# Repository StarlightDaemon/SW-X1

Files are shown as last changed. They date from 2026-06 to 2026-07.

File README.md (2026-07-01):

# Sidewinder X1 — Firmware & Tooling Maintenance Workspace

Locally-owned maintenance record for **one** Artillery Sidewinder X1 (Gen 1 Rev 1) being
recommissioned after ~5 years in storage. Self-contained: verified firmware source +
binaries, a documented configuration diff, matching TFT firmware, printed-part files,
wiring docs, and full upstream backups — all under this repo's control, independent of any
upstream GitHub repo's future activity.

> **Governing rule:** trust the hardware (`M115`/`M119`/`G29`) and the actual file
> contents — never a filename, README, or changelog. This ecosystem has repeatedly
> mislabeled capability. See [docs/verification-log.md](docs/verification-log.md).

---

## ▶ Start here
**[docs/GUIDE.md](docs/GUIDE.md)** — the ordered end-to-end build guide (parts → print →
wire → flash → verify → calibrate → map the warp). Everything below is reference for it.

## ⚠️ Headline finding (read before flashing anything)
The BLTouch build the project planned to flash — dgtaheno **`Marlin 2.1.2.1-X1-BLT.hex`** —
is **NOT Waggster-compatible as shipped.** Its `Configuration.h` leaves
`Z_MIN_PROBE_USES_Z_MIN_ENDSTOP_PIN` active *and* sets `Z_MIN_PROBE_PIN 19`, which
contradict: Marlin reads the probe on **Z-MIN**, not the **Z-MAX/pin-19** port the
Waggster mod wires to. Flashed as-is, the probe would never be seen.

**Flash instead — both ready now** (see [docs/install-runbook.md](docs/install-runbook.md)):
1. ★ **`firmware/build--X1-BLT-2.1.2.1-waggster-fixed/Marlin-2.1.2.1-X1-BLT-waggster-fixed.hex`**
   — dgtaheno's X1-BLT **rebuilt this session with the probe fix** (line 1279 commented →
   probe on Z-MAX/pin 19). Marlin 2.1.2.1, exact X1 geometry, compiled clean & verified. **or**
2. `firmware/reference--digant73-2.0.9.1-waggster-zmax/firmware.hex` — prebuilt, correct out
   of the box (UBL 7×7 — better for a heavily warped bed).

Then **verify on hardware** (`M119` probe toggle, `G29`) before trusting it.

## Current state of the printer
| | |
|---|---|
| Running firmware | Marlin 2.1.2.1, dgtaheno **X1 non-BLT** (`Marlin 2.1.2.1-X1.hex`), Oct 14 2023 |
| Leveling | **None compiled in** (verified via `M115`: `Cap:AUTOLEVEL:0`, `Z_PROBE:0`; `G29`→Unknown) |
| TFT | MKS TFT28 V4.0.27.x, dgtaheno companion build |
| Host | COM3 @ 250000, CH340; TFT "Disconnect" mode needed for host access |
| Calibration (live) | Hotend PID 17.07/1.51/48.25 · Bed PID 44.56/7.25/182.52 · E-steps 440.87 |

Hardware details: [docs/hardware-baseline.md](docs/hardware-baseline.md).
Calibration to preserve across reflash: [docs/calibration-baseline.md](docs/calibration-baseline.md).

## What's planned
Add a **genuine ANTCLABS BLTouch v3.1** via the **Waggster mod** (probe signal → Z-MAX /
pin 19, reusing the LED ribbon path; sacrifices the extruder LED). Sensor + 2 m cable
ordered. Mount in PETG; fan-duct remix on standby. Wiring: [wiring/README.md](wiring/README.md).

## Repository map
```
README.md                     ← you are here
docs/
  GUIDE.md                     ★ master ordered build guide — start here
  hardware-baseline.md         canonical hardware facts (do not re-derive)
  calibration-baseline.md      live PID / e-steps + host connection notes
  verification-log.md          M115 ground truth + source-inspection proofs ★
  configuration-diff.md        8-build comparison matrix + customizations ★
  open-questions.md            Q1/Q2/Q3 answered + remaining hardware items
  decisions.md                 decisions + rationale
  install-runbook.md           ★ flash-day step-by-step: wire → flash → verify → calibrate
firmware/
  running--dgtaheno-X1-nonBLT/      what's on the printer now (hex + headers)
  target--dgtaheno-X1-BLT/          as-shipped (⚠ probe forced to Z-MIN — do not flash)
  build--X1-BLT-2.1.2.1-waggster-fixed/  ★ recommended flash: X1-BLT rebuilt w/ probe fix
  reference--dgtaheno-Genius-BLT/   correct z-max routing but Genius bed (220²)
  reference--digant73-2.0.9.1-waggster-zmax/  ★ correct Waggster build (source+hex+pins)
  reference--digant73-2.0.9.1-mbl/  manual-mesh reference
  reference--peterrakolcza-2.1.2/   2.1.2-era binaries (no source)
  reference--artillery3d-stock/     manufacturer stock reference
  NOTES.md                          firmware map + MD5 fingerprints
tft-firmware/                  matching dgtaheno TFT update + a BTT-based option
printed-parts/                 mount+duct STLs (all vendored) — see BLTOUCH-MOUNT-OPTIONS.md
  waggster-bltouch-mount-duct/   Option A: blinkybill integrated mount+duct
  waggster-bltouch-mount/ + fan-duct-remix/  Option B: Waggster mount + alguiens duct
wiring/                        Waggster Mod - BLTouch v1.5.pdf + pin-mapping notes
calibration/                   Reset Settings.gcode (EEPROM reset)
archive/
  upstream-bundles/            full git bundles of all 4 upstreams (complete backup)
  SOURCES.md                   repo URLs, cloned commit SHAs, restore instructions
```
★ = start here.

## Next actions (in order)
> Flash-day checklist with exact commands: **[docs/install-runbook.md](docs/install-runbook.md)**.
1. Print Waggster mount (PETG); test-fit against the stock fan duct.
2. Wire the BLTouch per [wiring/README.md](wiring/README.md) (probe → Z-MAX/pin 19).
3. Flash a **correct** Waggster build (see Headline finding). Run the EEPROM reset
   (`calibration/Reset Settings.gcode` or `M502/M500`).
4. **Verify on hardware:** `M115` (Cap:Z_PROBE:1), `M119` (probe toggles), `G29` (runs).
5. Re-apply live calibration (`M301`/`M304`/`M92` then `M500`).
6. Set `M851` Z-offset; measure `NOZZLE_TO_PROBE_OFFSET` for the actual mount.
7. **Then** map the real bed warp (still unmeasured — see hardware-baseline.md).

## Deferred / out of scope
Z lead-screw lubrication; plastic→aluminium idler swap; all-metal heatbreak (current
~240 °C cap); empirical bed-warp mapping. **Out of scope:** Klipper/RPi/32-bit migration,
CNC tooling, 3D-modeling workflow.

## Provenance
All four upstreams cloned **2026-06-30**; commit SHAs and bundle-restore instructions in
[archive/SOURCES.md](archive/SOURCES.md). Firmware fingerprints in
[firmware/NOTES.md](firmware/NOTES.md).

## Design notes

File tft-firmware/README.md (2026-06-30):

# TFT firmware (MKS TFT28 V4.0)

Two TFT firmware options are collected here. They are **different firmware families** —
read before flashing.

## 1. `dgtaheno-SD-TFT-update.zip` — the matching companion (use this one to stay in sync)
This is the TFT firmware that **pairs with the dgtaheno Marlin build currently on the
printer** (MKS TFT28 V4.0.27.x era). It is the in-sync option: flash via SD card (copy
contents to SD root, power on, wait for the flash, reboot). MD5 `2efd1b209a9621e6e5b2325a192f87fb`.

## 2. `mks-tft28-1.27.x-patch9.5/` — community BTT-based firmware (different UI; optional)
From the peterrakolcza bundle: a **BIGTREETECH-TouchScreenFirmware**-based build
(`MKSTFT28.bin` + `config.ini` + `TFT28/` assets + language packs). MD5 of the bin
`49d9726547ffe74c7bdfa38ca11b03d1`.

- This is the **1.27.x** BTT TFT firmware line — a **different family** from the stock
  MKS TFT firmware, with full **BLTouch / mesh-editor / Marlin-mode** menus (note the
  `bltouch*.bmp`, `mesh_editor.bmp`, `marlin_mode.bmp` icons in `TFT28/bmp/`).
- Potentially useful **after** the BLTouch is installed (on-screen probe deploy/test,
  mesh tuning), **but flashing it replaces the entire TFT UI** the printer ships with.
  Treat as an optional, deliberate upgrade — not a drop-in patch. Test with the printer
  in a known state and keep option 1 on hand to revert.

> The printer currently runs the dgtaheno companion TFT firmware (per the handoff:
> MKS TFT28 V4.0.27.x, Jan-2022 era). Don't reflash the TFT casually — the TFT shares the
> serial bus with USB, so a half-flashed TFT can complicate host access. See
> [`../docs/calibration-baseline.md`](../docs/calibration-baseline.md) for the
> Disconnect-mode requirement.

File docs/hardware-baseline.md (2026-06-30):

# Hardware baseline — Artillery Sidewinder X1 (Gen 1, Rev 1)

Canonical hardware facts for this specific unit. **Do not re-derive or re-ask these.**

| Subsystem | Detail |
|---|---|
| Printer | Artillery Sidewinder X1, **Gen 1 Rev 1** (original US-launch hardware). Build volume **300 × 300 × 400 mm**. |
| Mainboard | **MKS Gen L v1.0**, ATmega2560 (8-bit AVR). |
| Stepper drivers | **TMC2100, standalone** (no UART). StealthChop on the extruder conflicts with LIN_ADVANCE — relevant when enabling features. |
| Extruder / hotend | Direct-drive **Titan Aero clone**, **Volcano-style** hotend, **PTFE-lined heatbreak → hard temperature cap ≈ 240 °C**. Extruder idler is plastic; an aluminium replacement is a cheap future swap (**not yet done**). |
| Bed | 300 × 300 mm **glass**, **AC-mains heater via SSR**. Reported **warped** — see warning below. |
| TFT | **MKS TFT28 V4.0**. |
| Z axis | Lead screw shows **stick-slip** (jump-then-smooth on first move after dormancy). Flagged for **lubrication** on the next maintenance pass — not yet addressed. |

## ⚠️ Bed-warp shape is UNMEASURED on this unit
The bed is *reported* warped, but the **specific shape/location has not been measured on
this physical bed.** An earlier AI-generated research report asserted a specific
"**30–50 mm raised band inset from the perimeter**" geometry — this was **rejected
mid-project as unverified**: it was inferred from generic community reports about the X1
model, not measured here. **Do not treat it as fact.** The real warp shape is to be
determined empirically once a working mesh-leveling system is in place.

## Known deferred maintenance (not yet done)
- Z lead-screw lubrication (stick-slip).
- Plastic → aluminium extruder idler swap.
- Empirical bed-warp mapping (needs working mesh leveling first).

## Out of scope (explicitly deferred)
- Klipper / Raspberry Pi / 32-bit board migration (long-term option, not part of this work).
- CNC / manual-machining tooling.
- 3D-modeling workflow.

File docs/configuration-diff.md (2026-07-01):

# Configuration comparison & customization diff

All values below are **first-hand from the actual `Configuration.h` files** (line numbers
are real). "Active" = uncommented `#define`; "commented" = `//#define`.

## Full comparison matrix

| Build (folder) | Bed X×Y×Z | Leveling (active) | Grid | BLTouch | Probe-pin routing | Hotend max | E-steps | Probe offset |
|---|---|---|---|---|---|---|---|---|
| `running--dgtaheno-X1-nonBLT` | 300×310×400 | **NONE** | — | off | Z-MIN (inert) | 275 | 445 | {10,10,0} vestigial |
| `target--dgtaheno-X1-BLT` | 300×310×400 | BILINEAR | 5×5 | on | ⚠ **CONTRADICTORY → Z-MIN** | 275 | 445 | {25.4,-26.4,-1} |
| `reference--dgtaheno-Genius-BLT` (`_BLT`) | 220×220×250 | BILINEAR | 5×5 | on | ✓ Z-MAX (pin 19) | 275 | 445 | {25.4,-26.4,-1} |
| `reference--dgtaheno-Genius-BLT` (`_BLT-295C`) | 220×220×250 | BILINEAR | 5×5 | on | ⚠ CONTRADICTORY → Z-MIN | **295** | 445 | {-44,-9,0} |
| `reference--digant73…waggster-zmax` | 305×305×400 | UBL | 7×7 | on | ✓ **Z-MAX (pin 19) — CANONICAL** | 275 | 445 | {33,-33,0} |
| `reference--digant73…(z_min, in bundle)` | 305×305×400 | UBL | 7×7 | on | ✓ Z-MIN | 275 | 445 | — |
| `reference--digant73-2.0.9.1-mbl` | 305×305×400 | MBL | 5×5 | off | Z-MIN (manual mesh) | 275 | 445 | — |
| `reference--artillery3d-stock` | 300×310×400 | NONE | — | off | none | 275 | 445 | — |

Marlin version: dgtaheno builds = **2.1.2.1**; digant73 + artillery3d = **2.0.x**.
Motherboard on every build: `BOARD_MKS_GEN_L`.

## The probe-pin defines, side by side (the crux)
The Waggster mod requires reading the probe on the **Z-MAX endstop = pin 19**. Three
`#define`s decide this. ✓ = correct for Waggster, ✗ = wrong/contradictory.

| Build | `Z_MIN_PROBE_USES_Z_MIN_ENDSTOP_PIN` | `USE_PROBE_FOR_Z_HOMING` | `Z_MIN_PROBE_PIN 19` | Net |
|---|---|---|---|---|
| **digant73 waggster (canonical)** | commented @1003 | active @1006 | active @1023 | **✓ Z-MAX** |
| dgtaheno `_BLT` (Genius) | commented @1279 | active @1282 | active @1299 | ✓ Z-MAX |
| **dgtaheno `-X1-BLT` (target)** | **active @1279** | active @1282 | active @1299 | **✗ → Z-MIN** |
| dgtaheno `_BLT-295C` | active @1279 | active @1282 | active @1299 | ✗ → Z-MIN |
| digant73 standard (z_min) | active @1003 | commented @1006 | commented @1023 | ✓ Z-MIN (by design) |

**Rule:** for Waggster, `Z_MIN_PROBE_USES_Z_MIN_ENDSTOP_PIN` must be **commented out** so
the `Z_MIN_PROBE_PIN 19` override takes effect. The X1-BLT build violates this.

## Customizations vs stock, explained (the dgtaheno X1 lineage)
Relative to `artillery3d-stock`, the dgtaheno X1 builds change:
- **Bed size** kept at X1 300×310×400 (Y is **310**, not 300 — matches stock). Z 400.
- **E-steps** default `{80, 80, 400, 445}` — E = 445 (extruder). *Live tuned value on the
  printer is 440.87; re-apply `M92 E440.87` after any flash.*
- **Hotend PID default** Kp 14.58 / bed Kp 244.21. *Live tuned values differ
  (Kp 17.07 hotend, 44.56 bed); re-apply after flash — see calibration-baseline.md.*
- **Hotend max temp** 275 °C. ⚠ **Hardware caps at ~240 °C** (PTFE-lined heatbreak) — do
  not exploit the firmware headroom until an all-metal heatbreak is fitted.
- **Leveling:** the running `-X1` build leaves all leveling OFF (the central surprise).
  The `-X1-BLT` build turns on BILINEAR 5×5 + BLTouch but mis-routes the probe pin (above).
- **NOZZLE_TO_PROBE_OFFSET** is build/mount-specific and must be re-measured for the
  actual printed BLTouch mount.

## Build the corrected X1 Waggster firmware (recommended recipe)
> ✅ **Path 2 below has already been built and verified this session** —
> `firmware/build--X1-BLT-2.1.2.1-waggster-fixed/Marlin-2.1.2.1-X1-BLT-waggster-fixed.hex`
> (see its `BUILD.md`). The recipe is kept here for reproducibility.

Two viable paths — see [decisions.md](decisions.md) for why:
1. **Flash digant73 `waggster_z_max` `firmware.hex` directly** (already correct: X1 bed
   305×305×400, UBL 7×7, Z-MAX pin 19, offset {33,-33,0}). Older Marlin 2.0.9.1 — fine for
   an 8-bit board. Then verify on hardware (§C of verification-log).
2. **Patch dgtaheno `-X1-BLT` source** if you want Marlin 2.1.2.1 + exact X1 geometry:
   - In `target--dgtaheno-X1-BLT/Configuration.h`, **comment out line 1279**
     (`Z_MIN_PROBE_USES_Z_MIN_ENDSTOP_PIN`). Leave 1282 and 1299 as-is.
   - (Optional) review `INPUT_SHAPING_*` in `Configuration_adv.h` — input shaping is
     atypical/often ineffective on 8-bit AVR; consider disabling. *(Not re-verified this
     session — confirm in source first.)*
   - Recompile (PlatformIO + Auto Build Marlin) against an upstream Marlin 2.1.2.1 tree
     with these headers dropped in (dgtaheno ships only the headers, not a full tree).
   - Re-measure and set `NOZZLE_TO_PROBE_OFFSET` for your mount.

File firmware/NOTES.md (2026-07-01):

# Firmware map & binary fingerprints

> Analytical conclusions (which build to flash, the X1-BLT probe-pin problem, grid sizes)
> live in [`../docs/verification-log.md`](../docs/verification-log.md),
> [`../docs/configuration-diff.md`](../docs/configuration-diff.md) and
> [`../docs/open-questions.md`](../docs/open-questions.md). This file is the inventory +
> fingerprints only.

## Folders
| Folder | What it is | Hardware fit |
|---|---|---|
| `running--dgtaheno-X1-nonBLT/` | **Exactly what is on the printer now.** `Marlin 2.1.2.1-X1.hex` + its config headers. No leveling, no probe (confirmed by `M115` on hardware). | X1 (300×300×400) ✓ |
| `target--dgtaheno-X1-BLT/` | The BLTouch build the user planned to flash. `Marlin 2.1.2.1-X1-BLT.hex` + config headers. **NOT cleanly Waggster-compatible as shipped** (probe forced to Z-MIN). | X1 ✓ |
| `build--X1-BLT-2.1.2.1-waggster-fixed/` | ★ **The recommended flash.** dgtaheno X1-BLT **rebuilt this session with the probe fix** (line 1279 commented → probe on Z-MAX/pin 19). Compiled clean for mega2560. See its `BUILD.md`. | X1 ✓ |
| `reference--dgtaheno-Genius-BLT/` | `_BLT` + `_BLT-295C` (Genius line). The `_BLT` config has the *correct* Z-max/Waggster probe-pin setup — but **Genius** bed geometry, not X1. | Genius (220×220) ✗ for X1 |
| `reference--digant73-2.0.9.1-waggster-zmax/` | **Canonical correct Waggster config** (full source: Configuration.h/_adv.h, Version.h, pins_RAMPS.h) + firmware.hex + readme/changes + cabling PDF. Older Marlin (2.0.9.1). | X1 ✓ |
| `reference--digant73-2.0.9.1-mbl/` | Manual mesh-bed-leveling reference config + hex. | X1 ✓ |
| `reference--peterrakolcza-2.1.2/` | 2.1.2-era **binaries only** (waggster z-max, standard z-min, mbl, standard) + lineage note. | X1 ✓ |
| `reference--artillery3d-stock/` | Manufacturer stock Configuration + pins_RAMPS. | X1 ✓ |

## Binary fingerprints (MD5)
| File | MD5 | Bytes |
|---|---|---|
| running `Marlin 2.1.2.1-X1.hex` | `03a6b3ab03f902d3f291fe2632c2f625` | 282 356 |
| target `Marlin 2.1.2.1-X1-BLT.hex` (buggy, as-shipped) | `01682ba04e424cc7f248516d22171a32` | 326 072 |
| **built** `…-X1-BLT-waggster-fixed.hex` (fixed, flash this) | `ddde4fc3f13dee23b9e6bad17e3bb845` | 326 346 |
| Genius `Marlin 2.1.2.1_BLT.hex` | `e15b19272bf80974d0ac603637631600` | 364 019 |
| Genius `Marlin 2.1.2.1_BLT-295C.hex` | `48e8630f788ac133769806b1f54a3b34` | 326 068 |
| digant73 waggster `firmware.hex` | `9ccdb52de85ebf6e9297d280aca5eb6c` | — |
| digant73 mbl `firmware.hex` | `232ce9bd4907167b71dd637137477f5c` | — |
| peterrakolcza 2.1.2 waggster_z_max | `f7a74392f91e9a3f5c60a4a1d16dd173` | — |
| peterrakolcza 2.1.2 standard_z_min | `342778293ce3ebde0cedbed781d19552` | — |
| peterrakolcza 2.1.2 mbl | `bd0324371ac9980e0f3f2b50b05c3d32` | — |
| peterrakolcza 2.1.2 standard | `fcce3111a245d0f035954702435c401a` | — |

## The "corrections pending validation" question (binary evidence)
In the dgtaheno repo root, the Genius-line build `Marlin 2.1.2.1_BLT.hex` and
`Marlin 2.1.2.1_BLT_corrections_pending on validation.hex` are **byte-identical**
(both MD5 `e15b19272bf80974d0ac603637631600`). So the "corrections pending" file is a
**relabeled copy** of `_BLT.hex`, not a distinct build. A separate dated artifact,
`..._corrections_pending on validation_180424.hex` (310 183 B), **is** a different,
earlier binary. None of these are in the **X1** family — `-X1-BLT.hex` (326 072 B) is a
separate, smaller binary. (Those two `corrections_pending` hexes are preserved only inside
the dgtaheno bundle in `../archive/upstream-bundles/`; they have no published source.)

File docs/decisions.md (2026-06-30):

# Decisions & rationale

Chronological record of decisions made for this printer, with the *why*. Newest first.

## 2026-06-30 — Firmware build for the Waggster BLTouch: don't flash `-X1-BLT` as-is
**Decision:** Do **not** flash dgtaheno `Marlin 2.1.2.1-X1-BLT.hex` for the Waggster mod
as shipped. Use one of:
1. **digant73 `waggster_z_max` `firmware.hex`** (correct out of the box), or
2. **dgtaheno `-X1-BLT` source with line 1279 commented out, recompiled** (if Marlin
   2.1.2.1 + exact X1 geometry is wanted).

**Why:** source inspection (verified by an independent agent panel) found `-X1-BLT`'s
probe pin is **internally contradictory** — `Z_MIN_PROBE_USES_Z_MIN_ENDSTOP_PIN` is left
active while `Z_MIN_PROBE_PIN 19` is also set, so Marlin reads the probe on **Z-MIN**, not
the **Z-MAX/pin-19** connector the Waggster mod wires to. As-shipped it would fail to see
the probe. digant73's `waggster_z_max` is the only config that is *both* correctly
Z-MAX-routed *and* X1-bed-sized. See [verification-log.md](verification-log.md) §B2 and
[configuration-diff.md](configuration-diff.md). **This is exactly the label-vs-reality
trap the project guards against — caught before flashing.**

**Tradeoffs:** option 1 is older Marlin (2.0.9.1, no input shaping — a plus on 8-bit) with
bed 305×305 and UBL 7×7; option 2 is current Marlin with exact 300×310 geometry and
BILINEAR 5×5 but requires a compile. Either way, `NOZZLE_TO_PROBE_OFFSET` must be
re-measured for the physical mount, and the probe must pass `M119`/`G29` on hardware.

**Do NOT use `_BLT-295C`** even though it raises the hotend cap to 295 °C: this printer's
PTFE-lined heatbreak caps at ~240 °C, so the extra headroom is a hazard, not a feature
(and that build also has the contradictory probe pin + Genius bed size).

## (Carried from handoff) — Add BLTouch via the Waggster mod
**Decision:** add a genuine BLTouch using the **Waggster mod** (reuses the extruder LED
ribbon path; maps probe → Z-MAX/pin 19), rather than self-compiling a manual MBL build.
**Why:** the running firmware has *no* leveling at all (verified, not assumed); a real
probe is more reliable than hand-MBL for a warped bed. Sacrifices the extruder LED.

## (Carried from handoff) — Sensor & cable sourcing
- **Genuine ANTCLABS BLTouch v3.1** from 3dprinteruniverse.com (official US reseller).
- **Avoid the "Artillery 3D ABL"** — ANTCLABS names it a counterfeit clone.
- **2 m** extension cable (buffer over 1 m given gantry travel / connector landing uncertainty).

## (Carried from handoff) — Mount material & duct contingency
- Print the Waggster mount in **PETG** (proximity to hotend; PLA can deform).
- Keep the **3DPrintBeginner improved fan duct** on standby in case the mount fouls the
  stock part-cooling duct. See [../printed-parts/](../printed-parts/).

## 2026-06-30 — Workspace strategy: vendored curation + full bundle archive
**Decision:** make this directory a standalone git repo. Vendor a *curated* set of the
relevant configs/binaries/docs for browsability, **and** archive complete `git bundle`
mirrors of all four upstreams under `archive/upstream-bundles/`.
**Why:** the mission requires survival independent of any upstream's future activity. The
bundles preserve every branch/tag/commit (verified restorable); the curated tree keeps the
day-to-day material readable. See [../archive/SOURCES.md](../archive/SOURCES.md).

## 2026-06-30 — Rejected: the "30–50 mm raised band" bed-warp geometry
**Decision:** treat the bed-warp shape as **unknown/unmeasured**.
**Why:** that specific geometry came from an AI report inferring generic community claims,
not a measurement of this bed. Map the real warp only once a working mesh exists.

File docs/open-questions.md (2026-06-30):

# Open questions — status

The handoff posed three "resolve by source inspection" questions plus a running
hardware-confirmation list. Status as of 2026-06-30.

## ✅ Q1 — Does `-X1-BLT` map the probe to Z-MAX (Waggster) or Z-MIN (standard)?
**ANSWERED (source-level, independently verified).** Neither cleanly. `-X1-BLT` is
**internally contradictory**: it leaves `Z_MIN_PROBE_USES_Z_MIN_ENDSTOP_PIN` **active**
(@1279) *and* sets `Z_MIN_PROBE_PIN 19` (@1299). Marlin honors the former and ignores the
latter → the probe is effectively read on **Z-MIN**, so the build is **NOT Waggster
(Z-MAX) compatible as-shipped.** The canonical correct Waggster config (digant73
`waggster_z_max`) comments that line out. **Fix:** comment line 1279, recompile.
Full evidence: [verification-log.md](verification-log.md) §B2, [configuration-diff.md](configuration-diff.md).
*Hardware confirmation still needed:* `M119` probe toggle.

## ✅ Q2 — Are the `_corrections_pending on validation` fixes folded into `X1-BLT`?
**ANSWERED.** **No.** The "corrections" = the Z-max probe-pin fix (commenting
`Z_MIN_PROBE_USES_Z_MIN_ENDSTOP_PIN`). Evidence chain:
- `Marlin 2.1.2.1_BLT.hex` is **byte-identical** (MD5 `e15b1927…`) to
  `…_BLT_corrections_pending on validation.hex` — the "corrections" build *is* `_BLT`.
- Source: only the Genius **`_BLT`** config has line 1279 commented (the fix). Both
  `-X1-BLT` and `_BLT-295C` still have it **active**.
- So the fix lives in the Genius `_BLT` build and was **never propagated** to the X1 build.
  (The separate dated `_180424.hex` is a distinct earlier binary; no source published.)

## ✅ Q3 — What `GRID_MAX_POINTS` is actually compiled in?
**ANSWERED (per active leveling system).**
- dgtaheno `-X1-BLT` (BILINEAR): **5×5**
- digant73 `waggster_z_max` (UBL): **7×7**
- digant73 `mbl` (MBL): **5×5**
- Running `-X1`: n/a (no leveling — this is *why* it was never confirmable on hardware before).

## ⏳ Still open — requires the physical printer (after BLTouch install + flash)
These cannot be settled from source. Full list in [verification-log.md](verification-log.md) §C.
- `M115` shows `Cap:AUTOLEVEL:1` / `Cap:Z_PROBE:1` after flashing a leveling build.
- **`M119` probe toggles** (definitive pin-routing proof).
- `G29` recognized + completes a mesh.
- BLTouch boot self-test passes.
- Physical `NOZZLE_TO_PROBE_OFFSET` measured for the actual printed mount.
- `_BLT-295C`'s real runtime behavior (it *does* set 295 °C in source — but irrelevant on
  this PTFE-limited hotend; do not use it for that reason).
- Whether `INPUT_SHAPING_*` (reportedly enabled in dgtaheno 2.1.x builds) actually helps
  on this 8-bit AVR — not re-verified in source this session.

## ⏳ Still open — empirical, deferred
- **Bed-warp shape** — unmeasured; map it only once a working probe/mesh exists.
  See [hardware-baseline.md](hardware-baseline.md) (the "30–50 mm raised band" claim is rejected).
- Z lead-screw lubrication; plastic→aluminium idler swap.

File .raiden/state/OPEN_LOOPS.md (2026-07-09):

# Open Loops

Work must be executed one loop at a time.

## LOOP-001: BLTouch mechanical install + firmware flash + verification

- Status: open
- Gate: hardware
- Scope: complete `docs/GUIDE.md` Phases 1-4 — mount the BLTouch, wire per
  the Waggster PDF, flash `firmware/build--X1-BLT-2.1.2.1-waggster-fixed/`,
  and run the Phase 3 verification gate (`M115` capability flags, boot
  self-test, `M119` probe toggle, `G29` recognized) before trusting the
  install.
- Readiness: blocked — waiting on the BLTouch v3.1 sensor and extension cable
  to arrive (both ordered per `docs/GUIDE.md` Phase 0).
- Closure condition: `M119` probe toggle confirmed live (the project's own
  definitive proof standard — "if it never toggles, STOP, wrong pin"), `G29`
  runs without error.

## LOOP-002: bed warp mapping + calibration

- Status: open
- Gate: hardware
- Scope: Phase 5 of `docs/GUIDE.md` — map the bed warp and calibrate. Not to
  be started before Phase 3's verification gate passes.
- Readiness: blocked on LOOP-001.
- Closure condition: bed warp mapped, calibration complete, printer verified
  ready for normal use.

## Provenance

- RAIDEN Instance installed 2026-07-08. No prior ledger to
  migrate from — this is the project's first RAIDEN state record.

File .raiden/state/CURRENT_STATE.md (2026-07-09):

# Current State

## Summary

- Confirmed: workspace is at the "status snapshot 2026-06-30" point recorded
  in `docs/GUIDE.md` — firmware corrected/verified, printed-part files
  vendored, wiring doc/TFT firmware/calibration baseline/upstream backups all
  in repo. Hardware work (everything from Phase 1 on) is pending on the
  BLTouch sensor arriving.
- Confirmed: the originally-planned firmware build
  (`dgtaheno Marlin-2.1.2.1-X1-BLT.hex`) was found NOT Waggster-compatible as
  shipped — it leaves the probe wired to Z-MIN instead of the Z-MAX/pin-19
  port the Waggster mod uses. A corrected build
  (`firmware/build--X1-BLT-2.1.2.1-waggster-fixed/`) was compiled this repo's
  own session and is the one to flash.
- Confirmed: bed warp is still unmeasured — deliberately deferred to Phase 5,
  not before.
- Confirmed: RAIDEN Instance installed 2026-07-08. Repo now
  has a GitHub remote (`StarlightDaemon/SW-X1`, public) as of this install —
  see `RAIDEN-ops/logs/DISTRIBUTION_LOG.md` and `Raiden-ops:LOOP-0021`. The 4 pre-install
  commits were re-authored from the operator's personal git identity to the
  `StarlightDaemon` fleet identity as part of this install (GitHub blocked
  the initial push over the private-email policy); no content changed.

## Constraints

- Confirmed: single-printer, single-operator maintenance record — not a
  general-purpose Sidewinder X1 project. Scope is this one physical unit.
- Confirmed: governing verification rule — trust the hardware, not
  filenames/READMEs/changelogs (this ecosystem has repeatedly mislabeled
  capability). See `docs/verification-log.md`.

## Provenance

- RAIDEN Instance installed 2026-07-08, following the scan and
  install recorded under `Raiden-ops:LOOP-0021`.
- State captured from `README.md` and `docs/GUIDE.md` at install time — not
  migrated from a prior ledger (this is the project's first RAIDEN state
  record).

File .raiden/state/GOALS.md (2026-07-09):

# Goals

## Primary Goal

Recommission one Artillery Sidewinder X1 (Gen 1 Rev 1) after ~5 years in
storage, adding BLTouch auto-leveling via the Waggster mod, with everything
under this repo's control (verified firmware source + binaries, configuration
diff, TFT firmware, printed-part files, wiring docs, upstream backups) —
independent of any upstream GitHub repo's future activity.

## Milestones

| # | Milestone | Status |
|---|---|---|
| 1 | RAIDEN Orientation | Done |
| 2 | Firmware build corrected & verified (probe-pin fix) | Done — `firmware/build--X1-BLT-2.1.2.1-waggster-fixed/` |
| 3 | Printed-part files vendored (mount/duct options) | Done |
| 4 | Wiring doc, TFT firmware, calibration baseline, upstream backups | Done |
| 5 | Parts ordered (BLTouch v3.1, extension cable) | In progress (per docs/GUIDE.md Phase 0) |
| 6 | Mechanical install + wiring | Pending — hardware work, waiting on BLTouch |
| 7 | Flash firmware, verify probe (`M119` toggle), `G29` | Pending |
| 8 | Bed warp mapping + calibration | Pending — explicitly deferred until Phase 5 |

## Governing Rule

Trust the hardware (`M115`/`M119`/`G29`) and actual file contents — never a
filename, README, or changelog. See `docs/verification-log.md`.

## Provenance

RAIDEN Instance installed 2026-07-08. Goals captured from
`README.md` and `docs/GUIDE.md` at install time.

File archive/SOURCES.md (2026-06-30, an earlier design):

# Upstream Sources — provenance & restore

All four upstream repositories were cloned **2026-06-30** as full `git clone --mirror`
clones and archived as git **bundles** under [`upstream-bundles/`](upstream-bundles/).
Each bundle contains **every branch, tag, and commit** of its upstream at clone time,
so this workspace stays complete and buildable even if an upstream repo is later
deleted, rewritten, or taken private. This is the upstream-independence guarantee for
the whole project.

| Local name | Upstream URL | Default branch | HEAD @ clone | Role in this workspace |
|---|---|---|---|---|
| dgtaheno-X1-marlin | https://github.com/dgtaheno/artillery-Genius-Genius_Pro-X1-Marlinfw | `Marlin-2.1.2.1` | `3d8709e7b438b949ae31ea842f0256367ba67599` | **Primary** — the currently-running firmware lineage (config headers + compiled .hex per variant) |
| digant73-releases | https://github.com/digant73/Artillery-Sidewinder-X1_releases_main_board | `master` | `b2574f48741b501ab93f956fdc40f4f83129a43a` | **Canonical pin-mapping reference** — full Marlin-2.0.x source for explicitly-labeled `waggster_mod_(z_max_used)` vs `standard_mod_(z_min_used)` vs `mbl`, plus the Waggster cabling PDF and a BLTouch bracket STL |
| peterrakolcza-upgrades | https://github.com/peterrakolcza/Artillery_Sidewinder_X1_Upgrades | `main` | `6848ac97ada88e754911ea27356bfe82c5befc3b` | 2.1.2-era waggster / z-min / mbl firmware **binaries** + community TFT firmware |
| artillery3d-stock | https://github.com/artillery3d/sidewinder-x1-firmware | `master` | `69c18e5bc7d8a8959120cfced1a256729702ddc7` | Manufacturer **stock reference** (pins, bed-size constants) |

### Correction to the handoff
The handoff described `digant73` as "an older, separate repo **by the same author**" as
`dgtaheno`. These are **different GitHub accounts** (`dgtaheno` vs `digant73`). The
digant73 firmware carries inline `// DIGA-Tech:` author comments. They are a closely
related but **separate** lineage — treated as independent here, not assumed identical.

## Restoring a full upstream from a bundle
```sh
git clone archive/upstream-bundles/dgtaheno-X1-marlin.bundle restored-dgtaheno
cd restored-dgtaheno && git branch -a       # all original branches/tags are present
```
Integrity can be re-verified at any time:
```sh
git bundle verify archive/upstream-bundles/dgtaheno-X1-marlin.bundle
```
Verified OK at archive time — the dgtaheno bundle restores all 10 refs, including
branches `Marlin-2.0.9.3`, `Marlin-2.1.2`, `Marlin-2.1.2.1`, `Marlin-2.1.2.5`.

Bundle sizes: dgtaheno ≈ 3.4 MB · digant73 ≈ 38 MB · peterrakolcza ≈ 50 MB · artillery3d ≈ 1 MB.

## Notes on upstream contents
- **dgtaheno** ships only the per-variant `Configuration.h` / `Configuration_adv.h`
  headers (under `src/`) plus precompiled `.hex` — **not** a full Marlin source tree.
  To rebuild, drop these headers into an upstream Marlin 2.1.2.1 checkout.
- **peterrakolcza**'s 2.1.2 firmware archives are **binary-only** (`firmware.hex`); no
  source `Configuration.h` is included. Its lineage note (`changes.txt`) states the FW is
  based on official Marlin 2.0.6.1 and modifies `pins_RAMPS.h`, `Configuration.h`,
  `Configuration_adv.h`, `Version.h`.
- **digant73** is the only source-bearing BLTouch reference (full Marlin-2.0.x trees).

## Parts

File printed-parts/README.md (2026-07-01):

# Printed parts

> **BLTouch mount + airflow:** see **[BLTOUCH-MOUNT-OPTIONS.md](BLTOUCH-MOUNT-OPTIONS.md)**
> for the researched + browser-verified recommendation (integrated blinkybill part
> thing:4606514, or Waggster mount + alguiens Futuristic duct thing:4368198) and the
> print-shop spec. That doc supersedes the older bare-mount + separate-duct split below.

| Folder | File present | Source | Print notes |
|---|---|---|---|
| `waggster-bltouch-mount-duct/` | blinkybill integrated **mount+duct** STLs (thing:4606514) | **Option A** | ★ single-piece mount+duct+BLTouch. PETG. |
| `waggster-bltouch-mount/` | Waggster originals + `SWX1-BLT-Bracket.stl` (digant73) | thing:3716043 + digant73 | Mount-only (pair with a duct for Option B). PETG. |
| `fan-duct-remix/` | alguiens **Futuristic** + **~180** ducts (thing:4368198 / 4360786) | **Option B** duct | Best cooling; pair with a Waggster mount. ⚠ CC BY-NC. |
| `gantry-square/` | `Gantry Square.STL` | peterrakolcza repo | Gantry-squaring jig. |
| `brackets/` | `Brackets.zip` | peterrakolcza repo | Misc upgrade brackets. |

## On the BLTouch mount
The **original** source is Thingiverse **thing:3716043** ("Waggster Mod BLTouch
Artillery sidewinder X1") — the file the whole ecosystem traces back to. Thingiverse
blocks automated download, so the binary STL is **not** vendored from there directly.
Instead, `SWX1-BLT-Bracket.stl` — a Waggster BLTouch bracket collected from the
**digant73** firmware repo (it ships in every `bltouch_waggster_mod_(z_max_used)` folder)
— is provided as a verified, locally-owned equivalent. Confirm fit against the original
thing:3716043 photos before printing. See `waggster-bltouch-mount/SOURCE.md`.

> Known fit issue: multiple users report the Waggster mount can interfere with the stock
> part-cooling fan duct. If a test-fit shows a collision, print the improved fan duct in
> `fan-duct-remix/` (it is designed specifically not to foul the Waggster mount).

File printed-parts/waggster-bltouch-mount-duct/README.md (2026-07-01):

# Waggster BLTouch mount + duct (integrated) — Option A

Integrated single-piece **mount + duct + BLTouch holder** for the Waggster (Z-max) build.
Source: **blinkybill, Thingiverse thing:4606514** — https://www.thingiverse.com/thing:4606514
(vendored here 2026-06-30 via the logged-in Thingiverse session).

| File | Bytes | MD5 | Print? |
|---|---|---|---|
| **`Fan_Mount_With_Duct_And_BL-Touch.stl`** | 1,121,684 | `5924d941e900916c538a2acee33f80c2` | ★ **print this** — the integrated mount+duct+BLTouch |
| `Fan_Mount_With_Duct_No_BL-Touch.stl` | 1,112,484 | `e2a4fb5d11cefebc35700881ba442b4e` | only if running without a BLTouch |
| `BLTouch_Mount_Slider.stl` | 141,184 | `50ba49ef68e507ace12434a9197aed1c` | spare slider mount (byte-identical to Waggster's original slider) |

Cooling is a single-sided/near-stock wrap. If first-layer/overhang cooling is weak on the
warped bed, keep the mount and switch to an alguiens duct in [`../fan-duct-remix/`](../fan-duct-remix/)
(Option B). Print spec + the full comparison: [`../BLTOUCH-MOUNT-OPTIONS.md`](../BLTOUCH-MOUNT-OPTIONS.md).

**Print:** PETG, genuine ANTCLABS BLTouch v3.1, do not scale, supports required for the
combined part. Verify licensing on the source page before a commercial print run.

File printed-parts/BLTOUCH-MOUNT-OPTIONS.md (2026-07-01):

# BLTouch mount + airflow — options, recommendation & print-shop spec

Goal: a BLTouch mount for the Waggster (Z-max) setup that **also handles part-cooling
airflow** (the bare Waggster bracket fouls / displaces the stock duct), to be **printed by
a print service** in PETG.

Researched + verified 2026-06-30 (multi-source workflow, then **hands-on Thingiverse
verification via the logged-in browser**). The browser pass corrected a bad lead:
**Thingiverse `thing:3972011` does NOT exist** ("removed or never existed") — it was a
hallucinated ID in the web research. Real, confirmed options below.

## The two real approaches
**A) One integrated part (simplest for a shop):**
**blinkybill — "Artillery Sidewinder/Genius Waggster Mod BL Touch Mount With Fan Duct"**
- Thingiverse **thing:4606514** — https://www.thingiverse.com/thing:4606514/files
- Contains 3 STLs (verified in the file list): **`Fan_Mount_With_Duct_And_BL-Touch.stl`**
  (the integrated mount + duct + BLTouch holder — *print this one*),
  `BLTouch_Mount_Slider.stl`, `Fan_Mount_With_Duct_No_BL-Touch.stl`.
- Waggster family, fits genuine BLTouch. One print, no separate duct. Cooling is a
  single-sided/near-stock wrap (adequate, not maximal).

**B) Best cooling, two parts (mount + a corrected duct):**
- **Mount:** the Waggster bracket — either the one already vendored here
  (`waggster-bltouch-mount/SWX1-BLT-Bracket.stl`, from digant73) or the canonical
  original (Thingiverse **thing:3716043**). *(Note: this bracket geometry is
  wiring-agnostic — the Z-MAX/Waggster distinction lives in the firmware + cabling, not
  the printed part. Verified: byte-identical to the z-min bracket.)*
- **Duct (pick one):**
  - **alguiens "Futuristic fan duct for BLTouch mount"** — Thingiverse **thing:4368198**
    (~251 makes, 5-star). Long reach *to the nozzle tip* → best actual tip cooling, but
    single-sided.
  - **alguiens "~180 just fan duct"** — Thingiverse **thing:4360786** (~47). Keeps
    bilateral ~180° coverage.
  - Both alguiens ducts are **CC BY-NC** → flag for a *commercial* print shop.

**Also exists (not on Thingiverse):** 3DPrintBeginner's combined ~180° mount+duct on
Printables (model 21261) / MakerWorld (23049) — the web research's original #1. Good ~180°
cooling but **login-walled** (you have Thingiverse, not necessarily Printables) and carries
a documented "duct sits a few mm too far from the nozzle" complaint (the very reason the
alguiens ducts exist). Left off the primary path because it's harder to obtain and no
better than B for cooling.

## Recommendation
- **Want one part the shop just prints →** A: blinkybill `Fan_Mount_With_Duct_And_BL-Touch.stl` (thing:4606514).
- **Want the best cooling for a warped bed →** B: Waggster mount (already in-repo) + alguiens **Futuristic** duct (thing:4368198).

Both are Thingiverse-obtainable with your login. For a *warped* bed where first-layer/
overhang cooling matters, **B with the Futuristic duct is the stronger pick**; A is the
lower-effort single print. Decide duct-to-nozzle adequacy after install (see caveats).

## Print-shop spec (hand this over)
- **Material: PETG (mandatory).** The part sits next to the hotend; PLA will creep/deform.
- **Layer height:** 0.15 mm (0.2 mm acceptable for speed).
- **Infill:** ~40–50% (structural mount near heat; don't go below ~30%).
- **Supports:** **the integrated combined part (A / the 3DPrintBeginner part) REQUIRES supports.**
  The standalone alguiens ducts and the flat Waggster/digant73 bracket are essentially
  support-free. Tell the shop which file they're printing.
- **Orientation:** carriage/mounting face flat to the bed; duct outlet supported (as the
  model loads). Ducts print on their flat/back face.
- **Quantity:** 1 (print 1–2 spare ducts if you expect eventual heat-creep on a near-hotend duct).
- **Fit/scale:** designed for a **genuine ANTCLABS BLTouch v3.1** push-fit boss — **do NOT
  scale.** If a clone is ever used, print ONE test unit and confirm the boss fully seats.
- **STEP/CAD:** none available for any of these (mesh/Tinkercad origin) — STL only.

## Verify-on-install caveats (only settleable on the real printer)
- **Duct-to-nozzle distance / tip cooling** — the recurring family complaint. If cooling is
  weak after mounting, keep the mount and swap to the alguiens Futuristic duct (thing:4368198).
- **BLTouch boss seat** — do one test print before any batch (especially with a clone probe).
- **Probe offset** — the Waggster-family firmware value is `{28,-33,0}`; the exact Z-offset
  must be calibrated on the assembled machine (`M851` + babystep). A *different* mount
  (e.g. SpankyToot X+60/Y+18) needs a different offset.
- **Carriage variant** — confirm standard vs large-display X1 carriage before printing if a
  design ships two variants.
- **Stock 4020 fan** — these use the stock fan; only the (not-recommended) Dual-5015 designs
  need added blowers.

## Acquisition status — ✅ all vendored locally (2026-06-30)
Every option's STL was pulled into this repo (verified valid binary STL, not HTML) via the
logged-in Thingiverse session. Nothing is link-only anymore.

| File (folder) | Thing | MD5 |
|---|---|---|
| `waggster-bltouch-mount-duct/Fan_Mount_With_Duct_And_BL-Touch.stl` | 4606514 | `5924d941e900916c538a2acee33f80c2` |
| `waggster-bltouch-mount-duct/Fan_Mount_With_Duct_No_BL-Touch.stl` | 4606514 | `e2a4fb5d11cefebc35700881ba442b4e` |
| `waggster-bltouch-mount-duct/BLTouch_Mount_Slider.stl` | 4606514 | `50ba49ef68e507ace12434a9197aed1c` |
| `fan-duct-remix/Artillery_Sidewinder_X1_Futuristic_fan_duct_for_BLTouch_mount.stl` | 4368198 | `2526bbb7daa2e1402ca6a950efd6f744` |
| `fan-duct-remix/Sidewinder_X1_Waggster_mod_BLtouch_fan_duct.stl` | 4360786 | `6ff7aec8a6e52e986150118c7e42a8ea` |
| `waggster-bltouch-mount/BLTouch_Mount_Adjustable.stl` | 3716043 | `384eb396c072f1fa33f8294ee7064e85` |
| `waggster-bltouch-mount/BLTouch_Mount_Slider.stl` | 3716043 | `50ba49ef68e507ace12434a9197aed1c` |
| `waggster-bltouch-mount/BLTouch_Calibration.stl` | 3716043 | `70756995821e21ca327f15e080605a21` |
| `waggster-bltouch-mount/SWX1-BLT-Bracket.stl` | digant73 repo | `e66f420a411adb69212e629429752aa1` |

**Licensing (important for a paid/commercial print shop):** the **alguiens** ducts
(thing:4368198, 4360786) are **CC BY-NC** — non-commercial. The blinkybill (4606514) and
Waggster (3716043) parts: verify the license on their Thingiverse page before a commercial
run. The 3DPrintBeginner combined part is not vendored (Printables/MakerWorld login-walled).

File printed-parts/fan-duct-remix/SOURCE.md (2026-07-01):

# Improved fan duct (Waggster-compatible) — source

Contingency part: an improved part-cooling duct by **3DPrintBeginner**, designed so it
does **not** interfere with the Waggster BLTouch mount and cools from ~180° instead of
one side. Print this only if a test-fit shows the BLTouch mount fouling the stock duct.

Binary STL is **not** vendored — Printables/Thingiverse require a session for download.
> **Superseded — see [../BLTOUCH-MOUNT-OPTIONS.md](../BLTOUCH-MOUNT-OPTIONS.md)** for the
> full browser-verified recommendation. Correction: the previously-listed Thingiverse
> `thing:3972011` **does not exist** (hallucinated ID; verified 404 in-browser 2026-06-30).

Real, verified duct sources:
- **alguiens "Futuristic fan duct for BLTouch mount"** — Thingiverse **thing:4368198**
  (best-validated, long reach to the nozzle tip; single-sided). *Recommended duct.*
- **alguiens "~180 just fan duct"** — Thingiverse **thing:4360786** (bilateral ~180° coverage).
  Both alguiens ducts are **CC BY-NC** (flag for a commercial shop).
- 3DPrintBeginner combined ~180° mount+duct (login-walled): Printables model 21261 —
  https://www.printables.com/model/21261-sidewinder-x1-waggster-mod-bltouch-with-improved-f
  · MakerWorld https://makerworld.com/en/models/23049 · write-up
  https://3dprintbeginner.com/sidewinder-x1-waggster-mod-bltouch-improved-fan-duct/

**TODO (manual):** download the STL from one of the above into this folder so the part is
fully local. Left as a manual step because these hosts block automated download.

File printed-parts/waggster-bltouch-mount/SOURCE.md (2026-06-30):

# Waggster BLTouch mount — source

- **Original (canonical):** Thingiverse **thing:3716043** — "Waggster Mod BLTouch
  Artillery sidewinder X1". https://www.thingiverse.com/thing:3716043
  - Thingiverse returns HTTP 403 to automated fetches, so the STL is **not** vendored
    from there. Download manually from the link above if you want the exact original.
- **Collected equivalent (in this folder):** `SWX1-BLT-Bracket.stl`, taken from the
  **digant73** repo (`artillery_swx1_marlin_fw_*/bltouch_waggster_mod_(z_max_used)/stl_files/`).
  This is a verified, locally-owned Waggster BLTouch bracket and the practical part to print.
- Full digant73 history (incl. this STL across all FW versions) is preserved in
  `../../archive/upstream-bundles/digant73-releases.bundle`.

**Material:** PETG recommended (proximity to hotend). **Test-fit** against the stock fan
duct before committing — if it collides, use `../fan-duct-remix/`.

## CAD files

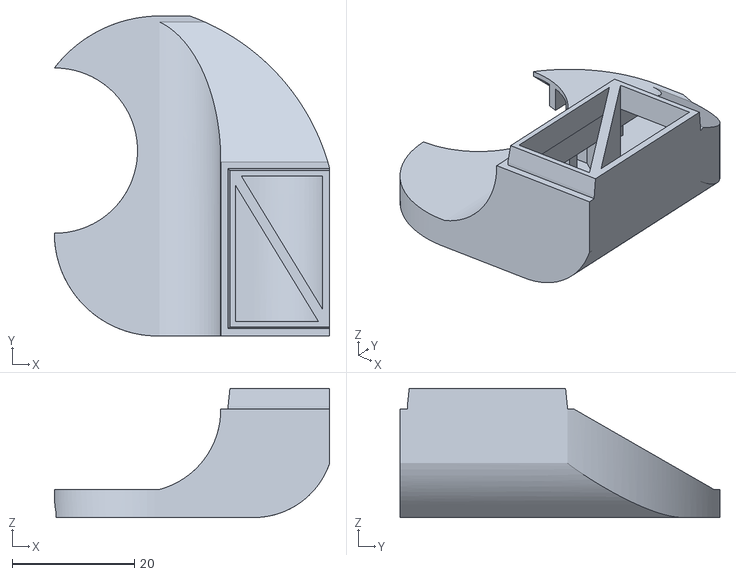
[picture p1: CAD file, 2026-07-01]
printed-parts/fan-duct-remix/Artillery_Sidewinder_X1_Futuristic_fan_duct_for_BLTouch_mount.stl
45.0 x 52.3 x 21.1

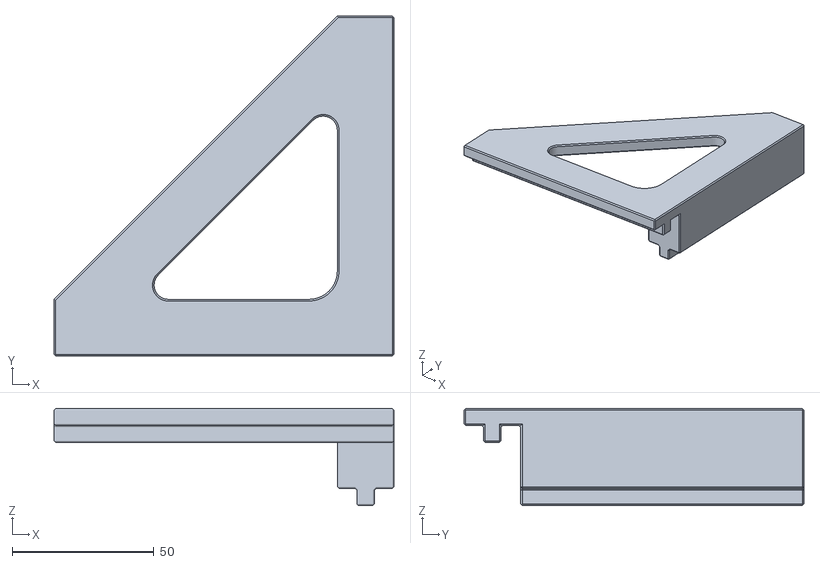
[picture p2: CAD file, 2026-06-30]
printed-parts/gantry-square/Gantry Square.STL
120.0 x 120.0 x 34.2

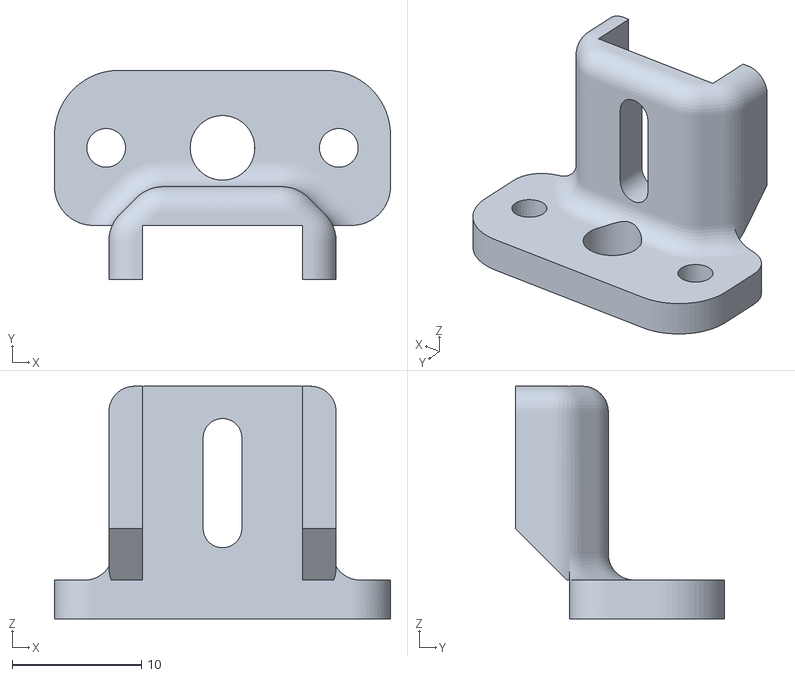
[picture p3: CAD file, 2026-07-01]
printed-parts/waggster-bltouch-mount-duct/BLTouch_Mount_Slider.stl
26.0 x 16.2 x 18.0

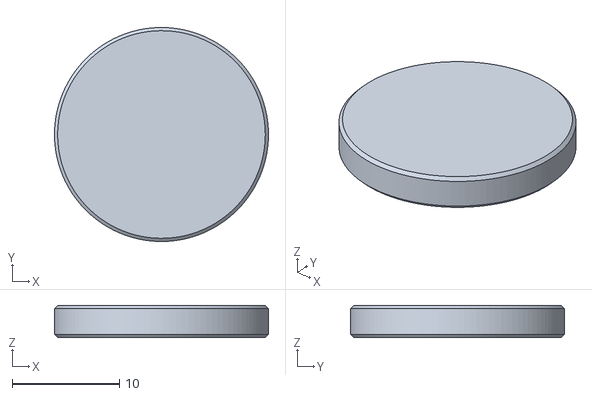
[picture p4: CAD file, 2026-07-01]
printed-parts/waggster-bltouch-mount/BLTouch_Calibration.stl
20.0 x 20.0 x 3.00

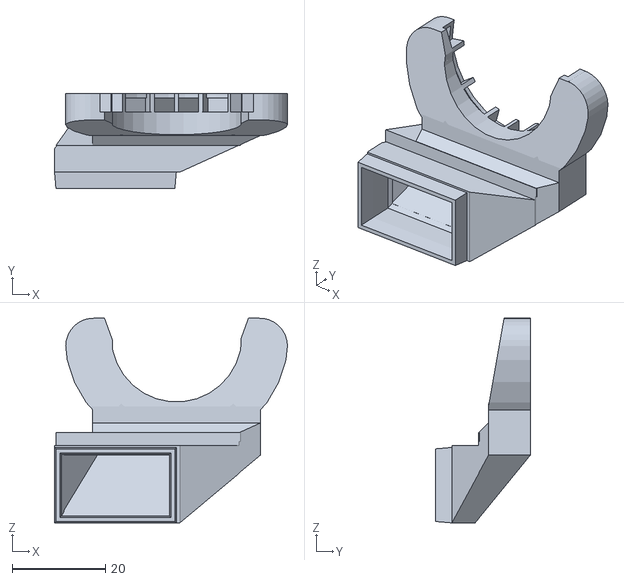
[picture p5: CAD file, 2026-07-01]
printed-parts/fan-duct-remix/Sidewinder_X1_Waggster_mod_BLtouch_fan_duct.stl
50.0 x 20.3 x 44.0

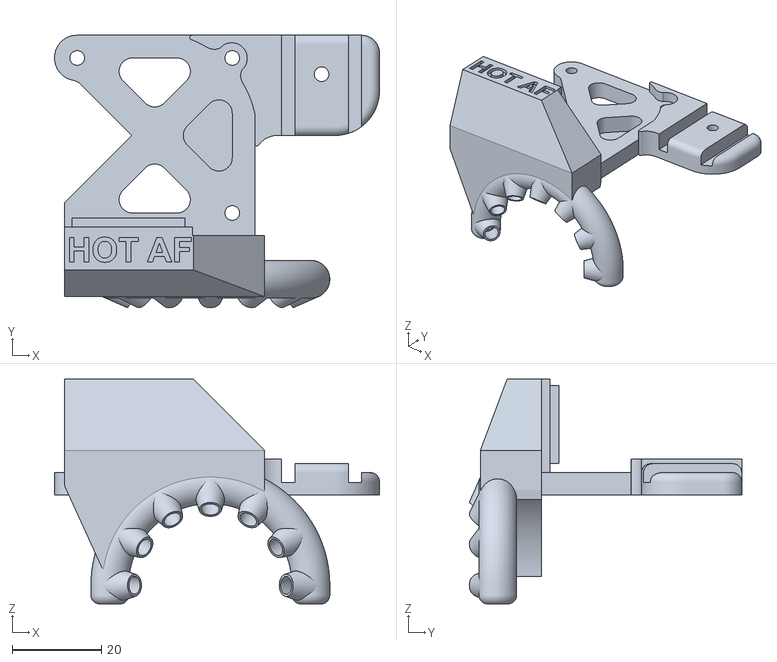
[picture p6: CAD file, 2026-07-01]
printed-parts/waggster-bltouch-mount-duct/Fan_Mount_With_Duct_And_BL-Touch.stl
72.9 x 61.2 x 50.5

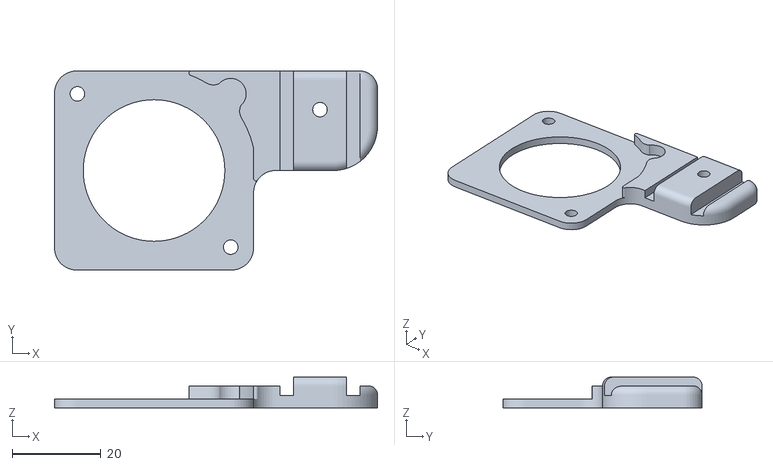
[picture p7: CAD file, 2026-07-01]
printed-parts/waggster-bltouch-mount/BLTouch_Mount_Adjustable.stl
73.0 x 45.0 x 7.00

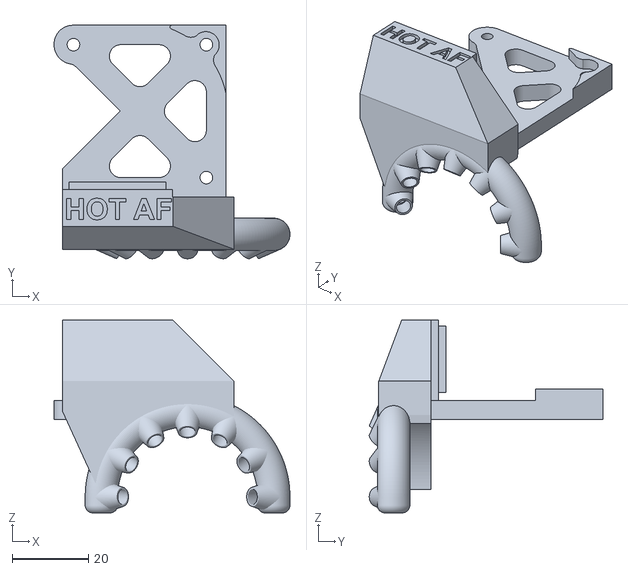
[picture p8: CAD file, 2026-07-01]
printed-parts/waggster-bltouch-mount-duct/Fan_Mount_With_Duct_No_BL-Touch.stl
61.8 x 61.2 x 50.5

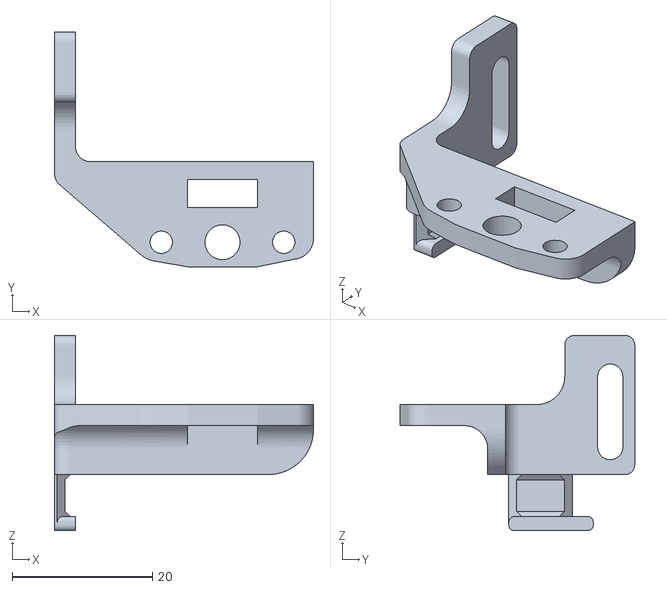
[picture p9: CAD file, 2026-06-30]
printed-parts/waggster-bltouch-mount/SWX1-BLT-Bracket.stl
37.0 x 33.5 x 27.9

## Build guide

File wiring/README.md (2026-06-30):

# Wiring — Waggster Mod (BLTouch on the Z-MAX / LED port)

**Primary document:** [`Waggster Mod - BLTouch v1.5.pdf`](Waggster%20Mod%20-%20BLTouch%20v1.5.pdf)
(collected from the digant73 repo; present in every `bltouch_waggster_mod_(z_max_used)/cabling/` folder).

## What the Waggster mod does (verified against digant73's labeled source)
Instead of running new wires through the gantry, the Waggster mod **reuses the existing
extruder LED ribbon cable path** to carry the BLTouch signal, and maps the BLTouch
**Z-probe signal to the Z-MAX endstop pin** — **pin 19** on RAMPS / MKS Gen L. This is
why digant73 labels the variant **`(z_max_used)`**. Trade-off: **the extruder LED light
is sacrificed.**

The firmware side of this mapping (which `#define`s must change to read the probe on
Z-MAX pin 19 rather than the default Z-MIN) is documented with exact line-level evidence
in [`../docs/configuration-diff.md`](../docs/configuration-diff.md) and
[`../docs/verification-log.md`](../docs/verification-log.md). **Wiring and firmware must
agree** — a Waggster-wired probe needs a Z-MAX-pin firmware build, or it will not be read.

## Sensor (already ordered)
- **Genuine ANTCLABS BLTouch v3.1** from 3dprinteruniverse.com (official US reseller).
- ⚠️ **Avoid** the "Artillery 3D ABL" sensor sold under the printer's own brand —
  ANTCLABS explicitly names it a **counterfeit clone**, not a genuine BLTouch.
- **2 m** extension cable purchased (buffer over the 1 m, given gantry travel and an
  uncertain connector landing point).

## Verify before trusting (hardware steps, not yet done)
After wiring + flashing a Z-MAX build:
1. `M119` — manually trigger/deploy the probe and confirm the **z_max** (or z_probe)
   endstop state changes. If nothing changes, the pin mapping is wrong.
2. `M115` — confirm `Cap:Z_PROBE:1` and `Cap:AUTOLEVEL:1`.
3. `G29` — must run (not "Unknown command").

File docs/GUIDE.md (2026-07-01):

# Sidewinder X1 — Master build & recommissioning guide

The single ordered walkthrough for taking this printer from its current state (running,
but **no bed leveling**) to a calibrated BLTouch auto-leveling machine via the Waggster
mod. Each phase links to the detail doc with exact commands/values. Do the phases in order;
don't pass a ⛔ gate that fails.

**Golden rule of this project:** trust the hardware (`M115`/`M119`/`G29`) and actual file
contents — never a filename, changelog, or web summary. See
[verification-log.md](verification-log.md).

---

## Status snapshot (2026-06-30)
| | |
|---|---|
| ✅ Firmware | Corrected, ready-to-flash build compiled & verified — `firmware/build--X1-BLT-2.1.2.1-waggster-fixed/` |
| ✅ Printed-part files | All mount/duct options vendored — `printed-parts/` ([options](../printed-parts/BLTOUCH-MOUNT-OPTIONS.md)) |
| ✅ Wiring doc, TFT fw, calibration baseline, upstream backups | in repo |
| ⏳ Hardware work | everything below Phase 1 — waiting on the BLTouch to arrive |
| ⏳ Bed warp | still **unmeasured** — mapped in Phase 5, not before |

---

## Phase 0 — Parts & printing (do now, before the sensor lands)
- [ ] **Sensor:** genuine ANTCLABS BLTouch **v3.1** (ordered). Avoid the "Artillery 3D ABL" clone.
- [ ] **Cable:** 2 m extension (ordered).
- [ ] **Print the mount** at your print service. Pick one:
  - **Option A (one part):** `printed-parts/waggster-bltouch-mount-duct/Fan_Mount_With_Duct_And_BL-Touch.stl`
  - **Option B (best cooling for a warped bed):** a Waggster mount from
    `printed-parts/waggster-bltouch-mount/` **+** `printed-parts/fan-duct-remix/Artillery_Sidewinder_X1_Futuristic_fan_duct_for_BLTouch_mount.stl`
  - **Spec sheet for the shop** (PETG, layers, supports, no-scale, licensing): [BLTOUCH-MOUNT-OPTIONS.md](../printed-parts/BLTOUCH-MOUNT-OPTIONS.md).
- [ ] **Back up current state:** connect host, run `M115` (note firmware) and `M503` (save the
      settings dump to a file). See host/TFT notes in [calibration-baseline.md](calibration-baseline.md).

## Phase 1 — Mechanical install (printer powered OFF)
- [ ] Fit the BLTouch to the printed mount; mount on the carriage; test-fit against the stock duct.
- [ ] Wire per the **authoritative** diagram — [wiring/README.md](../wiring/README.md) →
      `Waggster Mod - BLTouch v1.5.pdf`. Key mapping: **probe SIGNAL → Z-MAX endstop (pin 19)**,
      reusing the LED ribbon path (**sacrifices the extruder LED**). Follow the PDF for exact
      wire colours / the servo lead — don't guess pinouts.

## Phase 2 — Flash firmware
- [ ] Choose the build ([full table](../firmware/NOTES.md)):
  - ★ **`firmware/build--X1-BLT-2.1.2.1-waggster-fixed/Marlin-2.1.2.1-X1-BLT-waggster-fixed.hex`**
    (Marlin 2.1.2.1, exact X1 geometry, probe fix applied). **or**
  - `firmware/reference--digant73-2.0.9.1-waggster-zmax/firmware.hex` (UBL 7×7 — more mesh points).
  - ⛔ **Never** flash the unpatched `firmware/target--dgtaheno-X1-BLT/…` — it routes the probe to Z-MIN.
- [ ] TFT → **Disconnect** mode so the host owns the serial bus.
- [ ] Flash via Prusa Slicer → COM3. Then reset EEPROM: `M502` → `M500` → `M501`.

Exact command-by-command procedure: **[install-runbook.md](install-runbook.md)** §3.

## Phase 3 — ⛔ Verify before trusting (the whole point)
- [ ] `M115` → **`Cap:AUTOLEVEL:1`, `Cap:Z_PROBE:1`** (was 0/0).
- [ ] BLTouch boot self-test: pin deploys→retracts.
- [ ] **`M119` probe toggle** — `M401` deploy, push the pin by hand, `M119` reads TRIGGERED,
      `M402` retract. **If it never toggles, STOP — wrong pin.** This is the definitive proof.
- [ ] `G29` is recognized (was "Unknown command").

Full checklist + why: [install-runbook.md](install-runbook.md) §4, [verification-log.md](verification-log.md) §C.

## Phase 4 — Calibrate
- [ ] Re-apply saved calibration (values → [calibration-baseline.md](calibration-baseline.md)):
      `M301 P17.07 I1.51 D48.25`, `M304 P44.56 I7.25 D182.52`, `M92 E440.87`, `M500`.
- [ ] **Probe offset for your mount** — measure nozzle↔probe offset; set `M851` (Z) and
      `NOZZLE_TO_PROBE_OFFSET` (X/Y). The baked-in values are mount-specific, not authoritative.
- [ ] **Z-offset:** `G28` → paper/babystep → `M851 Z-…` → `M500`.
- [ ] `G28` → `G29` (build first mesh) → `M420 S1`. Add `M420 S1` after `G28` in your slicer start G-code.

## Phase 5 — Map the warp, first prints, tune
- [ ] Print a large single-layer bed-level test.
- [ ] **`M420 V`** — dump the probed mesh. **This is the first real measurement of the bed
      warp** (previously unmeasured; the "30–50 mm band" claim was rejected —
      [hardware-baseline.md](../docs/hardware-baseline.md)). Record it.
- [ ] If first-layer/overhang cooling is weak: keep the mount, swap to the alguiens
      **Futuristic** duct (`printed-parts/fan-duct-remix/`). If warp is severe, consider the
      digant73 UBL 7×7 firmware for more mesh points.

## ⚠ Safety
Keep real hotend temps **≤ ~240 °C** — the PTFE-lined heatbreak degrades above that even
though firmware caps allow 275 °C. Do **not** use the `_BLT-295C` build.

## Deferred maintenance (do opportunistically)
Z lead-screw lubrication (stick-slip), plastic→aluminium extruder idler, all-metal
heatbreak (to lift the 240 °C ceiling). Details: [hardware-baseline.md](hardware-baseline.md).

## Rollback
Re-flash `firmware/running--dgtaheno-X1-nonBLT/Marlin 2.1.2.1-X1.hex` for the known-good
pre-BLTouch state.

## Why these choices
Decision log with rationale: [decisions.md](decisions.md). Open questions (all answered by
source inspection) + remaining hardware items: [open-questions.md](open-questions.md).
Every firmware customization explained: [configuration-diff.md](configuration-diff.md).

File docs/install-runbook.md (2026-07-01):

# BLTouch install & verification runbook

Do this **in order** the day the BLTouch arrives. Boxes are checkpoints — don't proceed
past a failed one. Keep the current firmware handy to roll back
(`firmware/running--dgtaheno-X1-nonBLT/`).

---

## 0 · Pre-flight (before touching the printer)
- [ ] Confirm the sensor is a **genuine ANTCLABS BLTouch v3.1** (not the "Artillery 3D ABL" clone).
- [ ] Print the mount in **PETG** — `printed-parts/waggster-bltouch-mount/SWX1-BLT-Bracket.stl`.
      **Test-fit against the stock part-cooling duct.** If it collides, print the duct in
      `printed-parts/fan-duct-remix/` first.
- [ ] Gather: chosen firmware `.hex`, Prusa Slicer (flasher), USB cable, 2 mm hex, the 2 m extension.
- [ ] **Record current state** so nothing is lost: connect host (TFT → Disconnect mode
      first), run `M115` (note firmware) and `M503` (save the full settings dump to a file).

## 1 · Choose firmware
| Option | File | Marlin | Bed | Leveling | Notes |
|---|---|---|---|---|---|
| **A (recommended)** | `firmware/build--X1-BLT-2.1.2.1-waggster-fixed/…-waggster-fixed.hex` | 2.1.2.1 | 300×310×400 | Bilinear 5×5 | Current Marlin, exact X1 geometry, probe fix applied + built this session |
| **B (proven, best for heavy warp)** | `firmware/reference--digant73-2.0.9.1-waggster-zmax/firmware.hex` | 2.0.9.1 | 305×305×400 | **UBL 7×7** | Prebuilt & correct out of the box; more mesh points |
| ❌ Do NOT flash | `firmware/target--dgtaheno-X1-BLT/…-X1-BLT.hex` | 2.1.2.1 | 300×310×400 | Bilinear 5×5 | Probe forced to **Z-MIN** — won't see a Waggster-wired probe |

Both A and B route the probe to **Z-MAX / pin 19** (Waggster). For a badly warped bed, B's
UBL 7×7 resolves warp better; A can be bumped to 7×7 later (`GRID_MAX_POINTS`) if desired.

## 2 · Wire the BLTouch (printer **powered OFF**)
- [ ] Fasten the BLTouch to the printed bracket; mount on the carriage.
- [ ] Route the cable along the **existing extruder LED ribbon path** and connect per the
      **authoritative diagram**: [`wiring/Waggster Mod - BLTouch v1.5.pdf`](../wiring/Waggster%20Mod%20-%20BLTouch%20v1.5.pdf).
      The key mapping: the **probe SIGNAL goes to the Z-MAX endstop connector (pin 19)**;
      this reuses the LED port and **sacrifices the extruder LED**. Follow the PDF for the
      exact wire colors and the servo/control lead — do not guess pinouts.

## 3 · Flash
- [ ] TFT → **Disconnect** mode (Menu → Settings → Connection) so the host owns the serial bus.
- [ ] Prusa Slicer → *Configuration → Flash printer firmware* → select the chosen `.hex` →
      port **COM3** → **Flash**.
- [ ] After flashing, reset EEPROM to the new firmware's defaults: **`M502`** then **`M500`** then **`M501`**
      (or "print" `calibration/Reset Settings.gcode`).

## 4 · Verify the firmware BEFORE trusting it (the whole point of this project)
- [ ] **`M115`** → must now show **`Cap:AUTOLEVEL:1`** and **`Cap:Z_PROBE:1`** (was 0/0).
- [ ] **Boot self-test:** on power-up the BLTouch pin should deploy→retract (and blink). If
      not, fix control/servo wiring before anything else.
- [ ] **`M119` pin-routing proof (critical):** `M401` (deploy) → gently push the pin up by
      hand → `M119` should read the Z-probe / Z-MIN endstop **TRIGGERED**; release → `M402`
      (retract). **If `M119` never changes, STOP — the probe is on the wrong pin** (the exact
      failure mode the unpatched X1-BLT build would have). This is the definitive test.
- [ ] **`G29`** must be a recognized command (previously "Unknown command").

## 5 · Calibrate
- [ ] Re-apply the saved calibration (values in [calibration-baseline.md](calibration-baseline.md)):
      `M301 P17.07 I1.51 D48.25`, `M304 P44.56 I7.25 D182.52`, `M92 E440.87`, then `M500`.
- [ ] **Probe offset:** measure the physical nozzle↔probe-tip offset for *your* mount and set
      it (`M851` for Z; X/Y come from `NOZZLE_TO_PROBE_OFFSET`). The builds' baked-in offsets
      differ (A: {25.4,-26.4,-1}; B: {33,-33,0}) and are **not** authoritative for your mount.
- [ ] **Z-offset:** `G28`, then paper/babystep to set `M851 Z-…`, `M500`.
- [ ] `G28` → `G29` to build the first mesh → `M420 S1` to enable it. Add `M420 S1` after
      `G28` in your slicer's start G-code so leveling is applied every print.

## 6 · First print + finally map the warp
- [ ] Print a large single-layer bed-level test.
- [ ] `M420 V` to dump the probed mesh — **this is the first real measurement of the bed
      warp** (still unmeasured; the "30–50 mm band" claim was rejected). Record it; it drives
      any future glass shimming / manual-corner decisions.

## ⚠ Safety reminder
Keep real hotend temps **≤ ~240 °C** — the PTFE-lined heatbreak degrades above that even
though the firmware caps allow 275 °C. (Do not use the `_BLT-295C` build.)

## Rollback
Re-flash `firmware/running--dgtaheno-X1-nonBLT/Marlin 2.1.2.1-X1.hex` to return to the
known-good pre-BLTouch state.

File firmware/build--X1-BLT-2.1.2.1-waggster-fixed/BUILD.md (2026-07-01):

# X1-BLT 2.1.2.1 — Waggster-fixed build

A corrected, **ready-to-flash** firmware built this session (2026-06-30). It is dgtaheno's
`Marlin 2.1.2.1-X1-BLT` with the single probe-pin bug fixed, so the BLTouch is read on the
**Z-MAX / pin 19** connector the Waggster mod wires to.

## Artifact
- **`Marlin-2.1.2.1-X1-BLT-waggster-fixed.hex`** — 326,346 bytes, MD5 `ddde4fc3f13dee23b9e6bad17e3bb845`.
- For comparison, dgtaheno's official (buggy) `-X1-BLT.hex` is 326,072 bytes — a 274-byte
  difference, confirming this is a faithful rebuild of the same config **plus** the fix.

## The only change vs dgtaheno's source
`Configuration.h` line 1279, `Z_MIN_PROBE_USES_Z_MIN_ENDSTOP_PIN`, **commented out**.
Verified in the compiled tree:
```
1279 : //#define Z_MIN_PROBE_USES_Z_MIN_ENDSTOP_PIN   (was active → forced probe to Z-MIN)
1282 :   #define USE_PROBE_FOR_Z_HOMING               (active)
1299 :   #define Z_MIN_PROBE_PIN 19                   (active → Z-MAX endstop pin)
1336 :   #define BLTOUCH                              (active)
1878 :   #define AUTO_BED_LEVELING_BILINEAR           (active, 5×5)
```
This matches digant73's canonical `waggster_(z_max_used)` recipe. See
[../../docs/configuration-diff.md](../../docs/configuration-diff.md).

## Build result
- Env `mega2560` (ATmega2560). PlatformIO 6.1.19. **SUCCESS.**
- **Flash 45.7%** (116,020 / 253,952 B) — fits comfortably.
- **RAM 84.9%** (6,954 / 8,192 B) — high but valid. ⚠ Typical for Marlin + ABL on 8-bit;
  a reason **not** to enable extra features on this board. If you see erratic behavior,
  SRAM pressure is the first suspect.

## Reproduce
```sh
python3 -m venv pio-venv && ./pio-venv/bin/pip install platformio
git clone --depth 1 --branch 2.1.2.1 https://github.com/MarlinFirmware/Marlin.git marlin-2.1.2.1
#   (upstream commit 09d0b4d15228b3efb6fd765f1e1574f521df2e27)
cp Configuration.h Configuration_adv.h marlin-2.1.2.1/Marlin/    # the fixed headers in this folder
./pio-venv/bin/pio run -d marlin-2.1.2.1 -e mega2560
#   -> marlin-2.1.2.1/.pio/build/mega2560/firmware.hex
```
The `Configuration.h` / `Configuration_adv.h` in this folder are the exact (fixed) inputs.

## Before relying on it — hardware checks
Flashing is not proof. Run the [install runbook](../../docs/install-runbook.md) §4:
`M115` (Cap:Z_PROBE:1), **`M119` (probe toggles — the definitive pin-routing proof)**, `G29`.
Also set `NOZZLE_TO_PROBE_OFFSET`/`M851` for *your* physical mount — the baked-in
`{25.4,-26.4,-1}` is dgtaheno's value, not authoritative for your bracket.

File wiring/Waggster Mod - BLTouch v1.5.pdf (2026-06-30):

Artillery Sidewinder BLTouch v1.1 | Waggster Mod

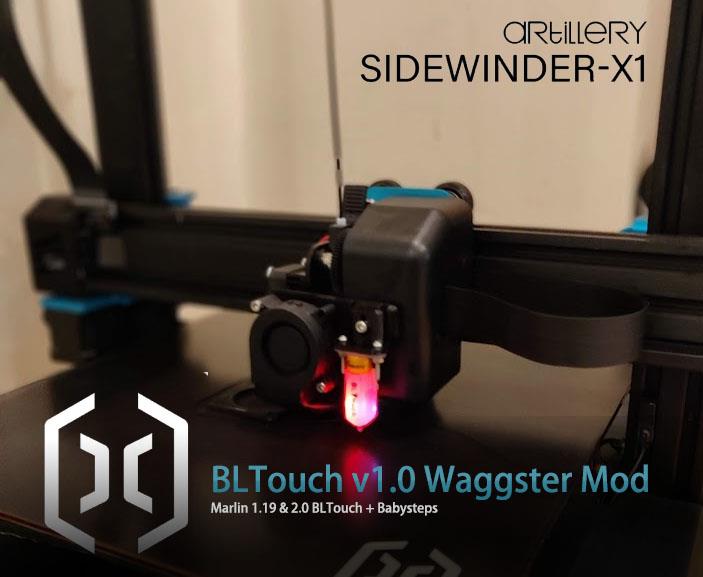
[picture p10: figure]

1 | P a g e

## BLTouch v1.1 Waggster Mod

## Includes

Wireless BLTouch wireless mod MKS Gen L1.0 Marlin 2.0.2 Firmware MKS 2.8 TFT LCD Firmware
PrusaSlicer Profiles

by Steve Wagg
(CdRsKuLL)

## REMEMBER TO REMOVE THE POWER CABLE

## What’s this mod all about?

This mod will enable you to attach a BLTouch using the existing LCD pins on the Artillery Sidewinder Pro X1. You will need to take the printer apart and relocate two cables which are the 3 pin and a 1 pin cable.

Items required

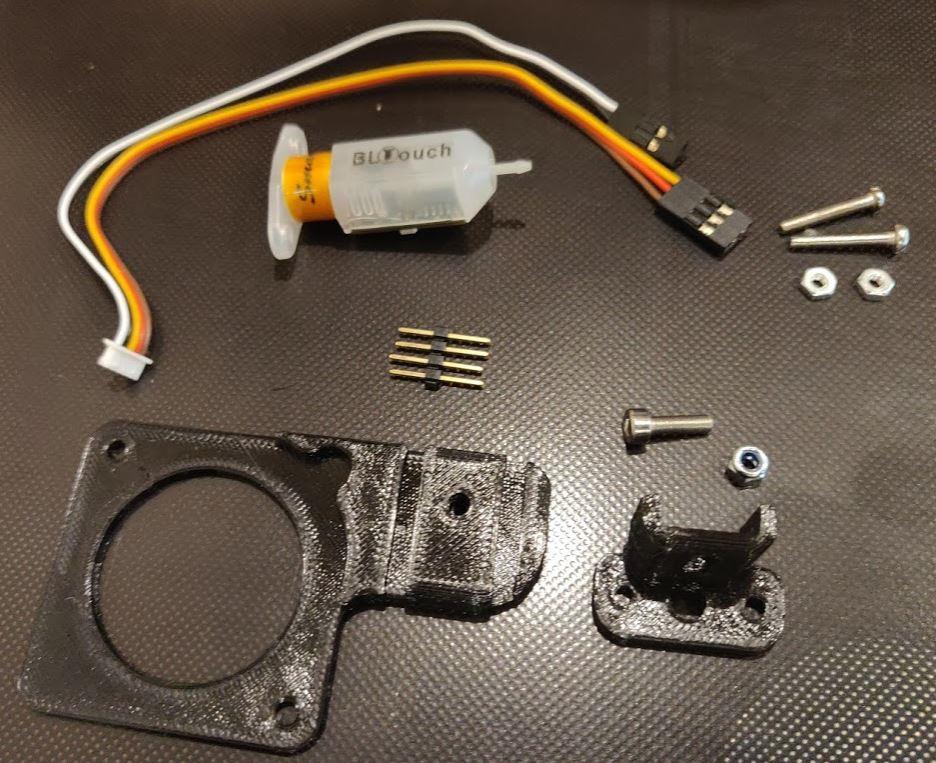
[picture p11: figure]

3D parts, BLTouch, 2 x mounting screws, 1 x M3x10 caphead screw with nyloc nut, 4 pin connector

## REMEMBER TO REMOVE THE POWER CABLE

Index

Mainboard LED cables relocation | page 3
BLTouch wiring | page 5
Mainboard firmware update | page 7
LCD firmware update | page 8
Setup BLTouch | page 9
Set your Z-Offset (part 1) | page 10
Autolevel G29 | page 11
Babysteps - Live Z-Offset adjust (part 2) | page 12

## Internal LED Cables

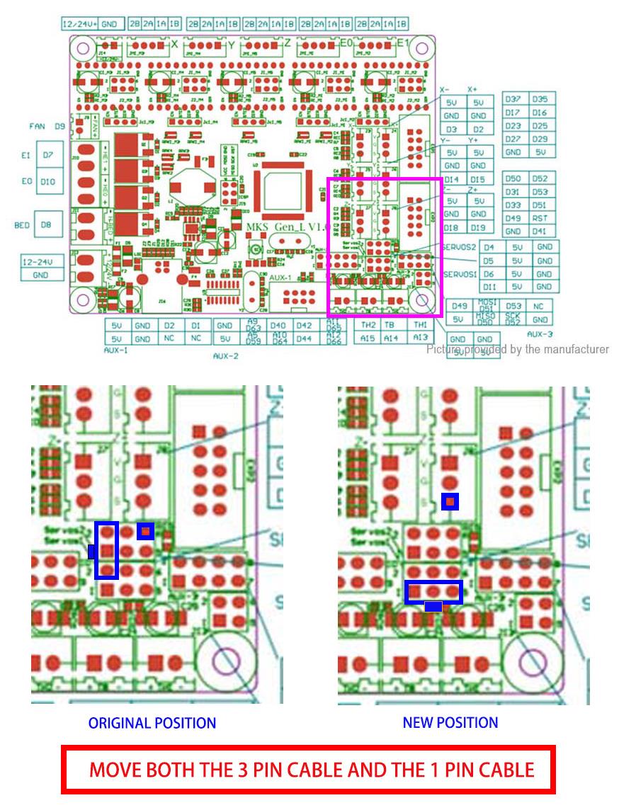
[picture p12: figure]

## Internal LED Cables

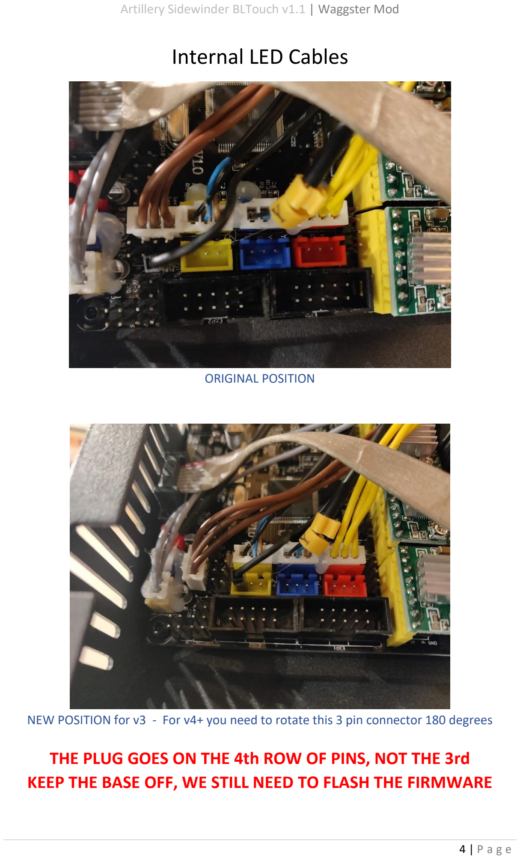
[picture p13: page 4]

ORIGINAL POSITION

NEW POSITION for v3 - For v4+ you need to rotate this 3 pin connector 180 degrees

## THE PLUG GOES ON THE 4th ROW OF PINS, NOT THE 3rd KEEP THE BASE OFF, WE STILL NEED TO FLASH THE FIRMWARE

## External LED BLTouch connection

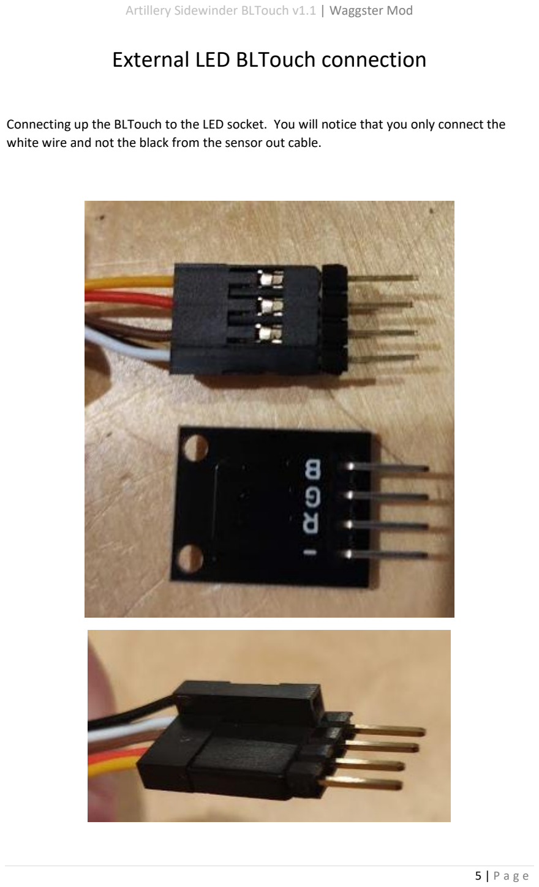
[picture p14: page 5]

Connecting up the BLTouch to the LED socket. You will notice that you only connect the white wire and not the black from the sensor out cable.

## External LED BLTouch connection

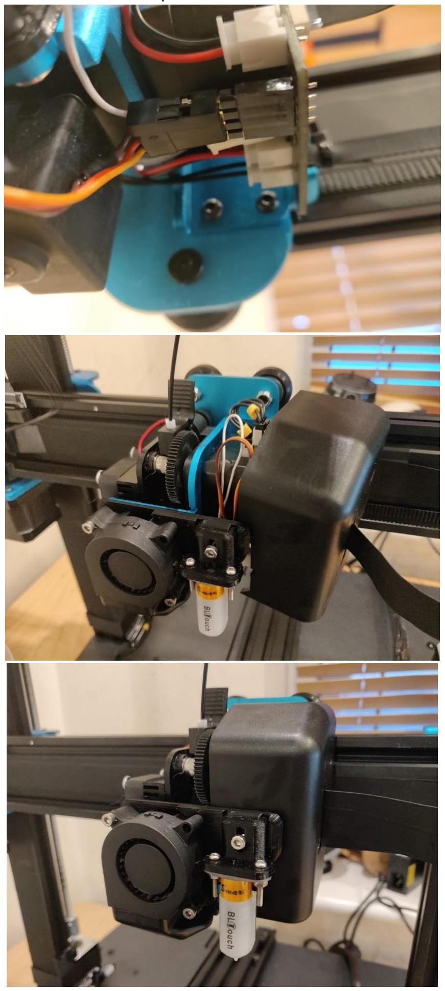
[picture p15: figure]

Complete the installation

## Flashing the mainboard firmware

Download and install Prusa Slicer 2.0 from https://www.prusa3d.com/drivers/
Click on the link that looks like this

Unplug the LCD screen from the mainboard

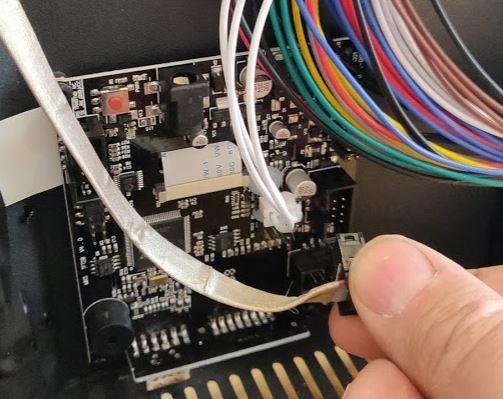
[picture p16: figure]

Connect your printer up via the USB lead, the printer power does NOT need to be on.

Start up Prusa Slicer 2.0 and select Configuration … Firmware Flasher and the below screen will appear.

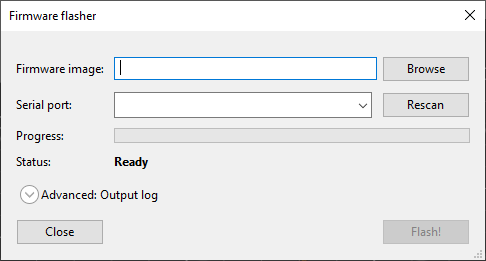
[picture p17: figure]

Select the serial port and choose Marlin 2.0.2 HEX file from the folder ‘Firmware -Main Board’.

## Flashing the LCD firmware

Once you have flashed the mainboard firmware then reconnect the LCD ribbon cable. Remove the USB cable and refit the base. Once back in one piece then plug the printer back in but do NOT turn it on yet.

Copy the files from the ‘Firmware - LCD Touchscreen’ folder into the root of a micro SD card.

Insert the card and turn the machine on. It will beep and start updating the LCD touchscreen. This takes about a minute and will look something like the below.

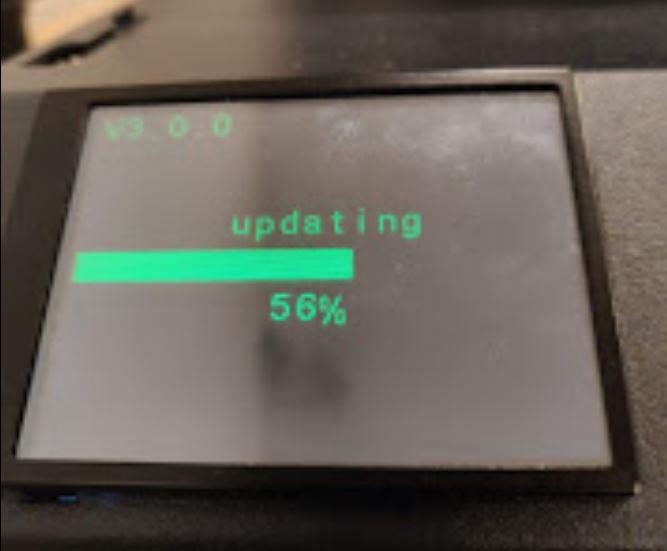
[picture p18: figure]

## IMPORTANT - ONCE COMPLETE YOU MUST RESET THE EEPROM Press Tools … More … Reset Eeprom

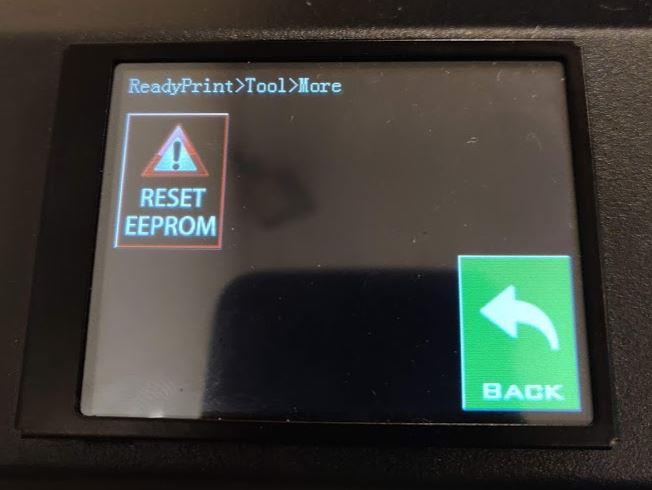
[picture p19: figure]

## Don’t forget to set the default FILE location back to USB… Click ‘SET’..’FILE’..’USB’

## Setup and using

Make sure you have flashed the mainboard and the touchscreen firmware. Once happy then you will need to set the height of the BLTouch.

Setting the height of the BLTouch

1. Move the BLTouch all the way down on its mount to start with (closer to the bed) and tighten up the height screw.
2. Power the machine on and select home from the LCD menu. (lower the Z axis)
3. Power off the machine, undo the BLTouch height screw and move it up to the top.
4. With the printer powered off, rotate both the Z axis motors and lower the nozzle until it touches the bed.
5. Put the 3mm calibration 3d printed part under the BLTouch and lower it until it touches the printed part.
6. Tighten up the height adjustment screw. Your BLTouch will now be 3mm above the nozzle when retracted. Then, raise the nozzle a few mm’s away so you don’t damage your bed by twisting the motors again.

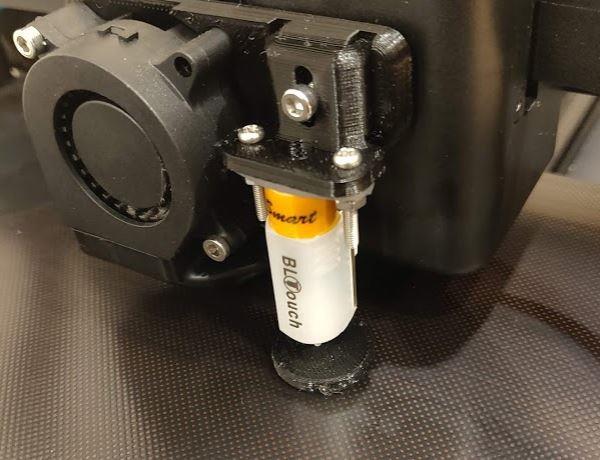
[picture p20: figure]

## Setting your Z-Offset (part 1)

I’ve tried to make this as easy as possible. You can set the Z-Offset completely from the touchscreen. After you have set the height of your BLTouch from the previous page you need to set the Z-Offset. This is the distance from the trigger point on the BLTouch to the bottom of the nozzle.

1. Turn the printer on.
2. Press ‘Tools’ then the ‘More’ button
3. If you haven’t done already then press the ‘RESET EEPROM’. You need to do this because you have updated the mainboard firmware, most likely to a different version.
4. Press the ‘START Z-OFFEST’
5. Use a piece of paper and adjust the nozzle height by pressing the up and down buttons.
6. Once you can feel it grabbing the paper then remove the paper and press the ‘MOVE DOWN’ button TWO MORE TIMES. Press back

Your Z-Offset height will now be set.

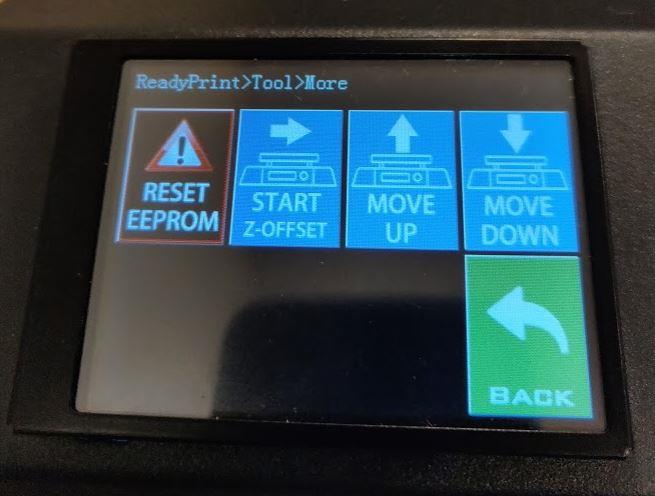
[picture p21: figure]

## Autolevel (G29)

Now you have added a BLTouch you can run an autolevel routine before every print. This is quite easy to do with a simple G29 command. Depending which slicer you use you will need to edit the Start GCODE script. Make sure you add it AFTER the G28; If you are using the included Prusa profile, then this has already been done. You can also run this from the LCD menu and it will remember the mesh recorded.

In Cura you add the G29 in the Machine Settings page

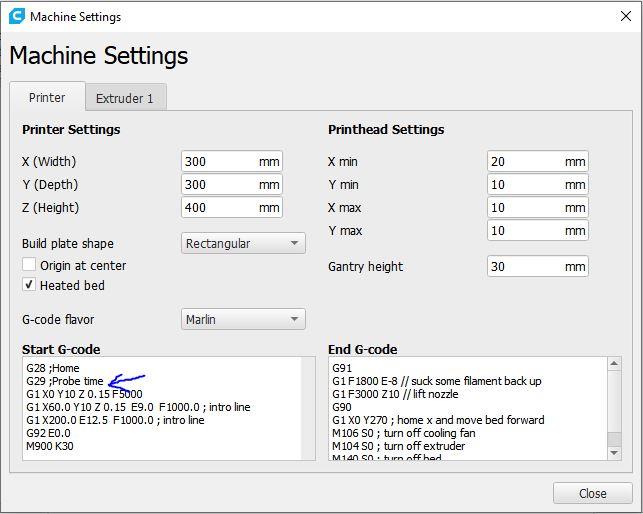
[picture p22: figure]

In Simplify3D you add the G29 in the FFF settings

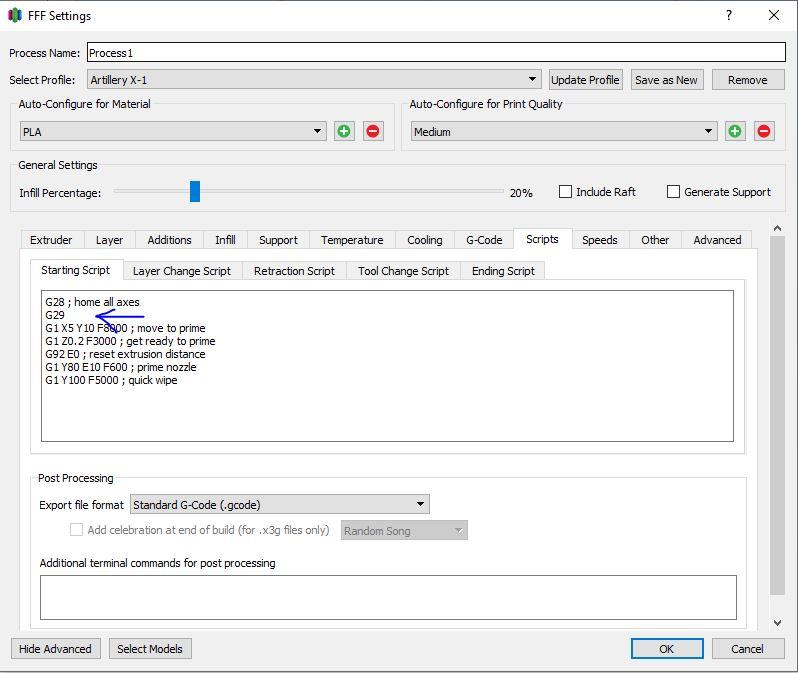
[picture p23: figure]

## Babysteps -Live Z-Offset adjust (part 2)

Babysteps is a bit of a fancy name but we will be using it for live Z-offset adjust. This function allows you to alter your first layer height LIVE, as it’s printing. It’s really easy to use and it will save your settings ready for your next print so you will not have to do it each time.

1. Start a print with a large 1st layer. Make sure you have sliced it using the G29 auto level command as on the previous page.
2. When it starts printing press the ‘OPTIONS’ then ‘MORE’ button.
3. Adjust the Z-Offset height if you need to by the UP / DOWN buttons. It autosaves the position. Be careful not to lower the nozzle to much as it will damage your bed.

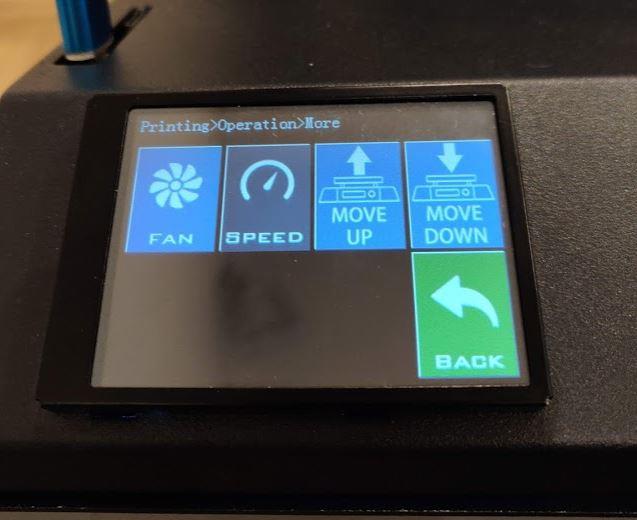
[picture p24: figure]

Babysteps adjustment

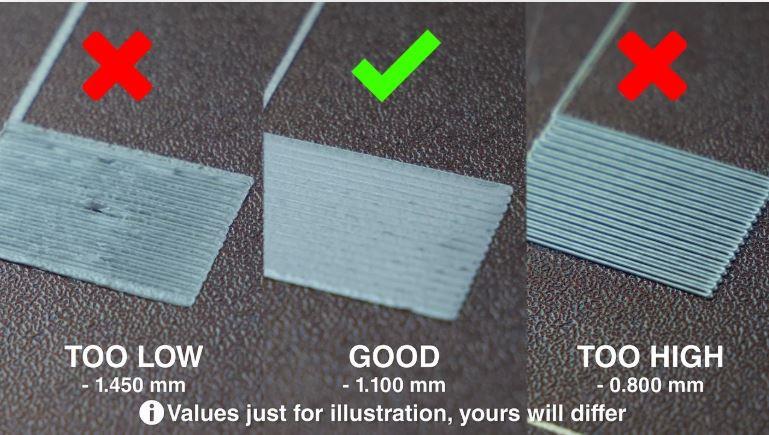
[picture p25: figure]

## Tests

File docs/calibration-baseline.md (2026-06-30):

# Calibration baseline

These are **live values read from the printer this session** (after an EEPROM reset),
i.e. the current runtime/EEPROM state — **not** firmware compile-time defaults. Preserve
them across any reflash: re-apply with `M301`/`M304`/`M92`, then `M500`.

| Parameter | Value | Re-apply with |
|---|---|---|
| Hotend PID | **Kp 17.07 · Ki 1.51 · Kd 48.25** | `M301 P17.07 I1.51 D48.25` |
| Bed PID | **Kp 44.56 · Ki 7.25 · Kd 182.52** | `M304 P44.56 I7.25 D182.52` |
| E-steps | **440.87 steps/mm** | `M92 E440.87` |
| (then save) | | `M500` |

- An **EEPROM reset was performed this session before** the above values were measured,
  so they reflect a clean baseline.
- Compare these against the **firmware compile-time defaults** in
  [`configuration-diff.md`](configuration-diff.md) — if a reflash changes the defaults,
  these EEPROM values must be re-applied or re-tuned.

## Host connection (Windows)
- Port **COM3**, baud **250000**, **CH340** USB driver.
- The **TFT shares one serial bus with USB** on the MKS Gen L v1.0. The TFT's built-in
  **"Disconnect"** mode (Menu → Settings → Connection) must be active for clean
  Pronterface/host access. This is a **known hardware limitation** of this board, not a
  bug. Confirmed working live this session.

## To capture on the next session (not yet recorded)
- Full `M503` dump (steps/accel/jerk/feedrate, Z-probe offset once BLTouch is in).
- XY steps/mm, acceleration & jerk/junction-deviation values.
- Filament-sensor and any input-shaping values if enabled.

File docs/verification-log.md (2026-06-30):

# Verification log

The governing rule of this project: **trust the hardware and the file contents, never a
filename, README, or changelog.** This log records what was actually checked and how.

---

## A. Hardware ground truth (live, this printer, this session)
Interrogated directly over USB (COM3 @ 250000, CH340; TFT in Disconnect mode):

- Running firmware: **Marlin 2.1.2.1, dgtaheno X1 non-BLT build** (`Marlin 2.1.2.1-X1.hex`), compiled Oct 14 2023.
- `M115` capability report: **`Cap:AUTOLEVEL:0`, `Cap:Z_PROBE:0`, `Cap:LEVELING_DATA:0`.**
- `G29` → **"Unknown command."**
- **Conclusion:** the running firmware has *zero* bed-leveling compiled in — not MBL, not
  ABL — despite the upstream README listing "Manual Bed leveling" as a family feature.
- TFT: MKS TFT28 V4.0.27.x, dgtaheno companion build. Serial shares the USB bus
  (MKS Gen L v1.0 hardware limitation); TFT "Disconnect" mode confirmed working for host access.

## B. Source-inspection verification (this session)
Method: all four upstream repos cloned in full; the running build's config plus 7 other
candidate configs read directly; the load-bearing `#define`s grepped first-hand (active
vs commented), then a 14-agent verification workflow independently re-read the same files
and three central claims were checked by independent skeptics. Line numbers below are
first-hand from the actual `Configuration.h` files.

### B1. The running build matches the hardware (no leveling) — CONFIRMED
`src/Marlin 2.1.2.1-X1/Configuration.h`: every leveling selector commented
(`//#define AUTO_BED_LEVELING_3POINT/LINEAR/BILINEAR/UBL` @1876–1879,
`//#define MESH_BED_LEVELING` @1880), `//#define BLTOUCH` @1336,
`//#define USE_PROBE_FOR_Z_HOMING` @1282. **Exactly consistent with `M115`.** This closed
the loop: the firmware really is leveling-less, not mislabeled-but-capable.

### B2. ⚠ The planned BLTouch build is mis-wired for Waggster — CONFIRMED (independent verdict: *confirmed*)
`src/Marlin 2.1.2.1-X1-BLT/Configuration.h` (the build the user planned to flash):
- `#define Z_MIN_PROBE_USES_Z_MIN_ENDSTOP_PIN` **active** @1279
- `#define Z_MIN_PROBE_PIN 19` **active** @1299
- `#define USE_PROBE_FOR_Z_HOMING` active @1282, `#define BLTOUCH` active @1336

These two are **mutually contradictory.** In Marlin, when
`Z_MIN_PROBE_USES_Z_MIN_ENDSTOP_PIN` is enabled the probe is forced onto the **Z-MIN**
pin and the explicit `Z_MIN_PROBE_PIN 19` (Z-MAX) override is **ignored**. The Waggster
mod wires the BLTouch signal to the **Z-MAX / pin-19** connector — so with this build
**as-shipped, Marlin would read the probe on the wrong (Z-MIN) pin and never see it.**

**Canonical contrast** — digant73's explicitly-labeled `bltouch_waggster_mod_(z_max_used)`
does it correctly: `//#define Z_MIN_PROBE_USES_Z_MIN_ENDSTOP_PIN` **commented** @1003
(its own comment: *"disabled due to usage of probe on Z max endstop"*) +
`#define USE_PROBE_FOR_Z_HOMING` @1006 + `#define Z_MIN_PROBE_PIN 19` @1023.

**Fix:** comment out line 1279 in the X1-BLT source and recompile — it then equals the
canonical Waggster recipe. **Hardware proof still required:** `M119` with the probe
deployed/retracted must show the endstop state toggle (see §C).

### B3. The "corrections pending validation" question — RESOLVED
- Binary fact (my direct MD5): `Marlin 2.1.2.1_BLT.hex` ≡ `Marlin 2.1.2.1_BLT_corrections_pending on validation.hex` (both `e15b1927…`) — **byte-identical**; the dated `_180424.hex` differs. So "corrections pending" = a relabeled copy of `_BLT.hex`.
- Source fact: the **only** dgtaheno BLTouch config with the **correct** Z-max routing
  (line 1279 *commented*) is the Genius **`_BLT`** build. Both `-X1-BLT` **and**
  `_BLT-295C` leave line 1279 **active** (contradictory).
- **Therefore:** the "correction" embodied in `_BLT.hex` is precisely the Z-max probe-pin
  fix, and it was **never propagated** into the `-X1-BLT` build (nor `_BLT-295C`). The
  corrections are **not** folded into the X1-BLT firmware.

### B4. Grid points (for the active leveling system) — CONFIRMED
- `-X1-BLT` (AUTO_BED_LEVELING_BILINEAR): **5×5** (`GRID_MAX_POINTS_X 5` @1958, in the LINEAR/BILINEAR block)
- digant73 waggster (AUTO_BED_LEVELING_UBL): **7×7** (`GRID_MAX_POINTS_X 7` @1609, in the UBL block)
- digant73 mbl (MESH_BED_LEVELING): **5×5** (@1629, in the MBL block)
The running `-X1` value is moot (no leveling active). This finally answers the grid
question that could never be confirmed on hardware (the running hex had no leveling at all).

### B5. Bed / temp / motion constants (first-hand grep)
| Build | Bed X×Y×Z | Hotend max | E-steps | Hotend Kp / Bed Kp (fw default) |
|---|---|---|---|---|
| dgt-X1 (running) | 300×310×400 | 275 | 445 | 14.58 / 244.21 |
| dgt-X1-BLT (target) | 300×310×400 | 275 | 445 | 14.58 / 244.21 |
| dgt _BLT (Genius) | 220×220×250 | 275 | 445 | 9.31 / 92.46 |
| dgt _BLT-295C (Genius) | 220×220×250 | **295** | 445 | 9.31 / 92.46 |
| digant73 waggster z_max | 305×305×400 | 275 | 445 | 22.20 / 10.00 |
| artillery3d stock | 300×310×400 | 275 | 445 | — |

⚠ Every firmware hotend cap (275, and 295 in the 295C build) **exceeds this printer's
~240 °C PTFE-lined heatbreak limit.** Firmware permitting 275/295 °C does not make it safe
on this hardware — keep real hotend temps ≤ ~240 °C until the heatbreak is replaced with
an all-metal one.

## C. Still requires the physical printer (do NOT assert until checked)
1. `M115` after flashing a leveling build → expect `Cap:AUTOLEVEL:1`, `Cap:Z_PROBE:1`.
2. **`M119` with the BLTouch deployed vs retracted → the endstop state must toggle.** This
   is the definitive proof the probe is read on the correct pin (the exact thing the
   X1-BLT contradiction would break).
3. `G29` must be recognized and complete a mesh.
4. BLTouch boot self-test (servo/control wiring).
5. Physical `NOZZLE_TO_PROBE_OFFSET` measured for the actual printed mount (builds disagree:
   X1-BLT `{25.4,-26.4,-1}`, digant73 `{33,-33,0}`, 295C `{-44,-9,0}` — must match *your* mount).
6. `G28` with Z-safe-homing: probe deploys before Z descends, homes at bed center without crashing.
7. Re-apply EEPROM calibration (PID, E-steps) — see [calibration-baseline.md](calibration-baseline.md).

## D. Methodology note
14 verification agents (≈665k tokens) profiled all 8 configs, diffed the Waggster vs
standard pin mapping, and three independent skeptics re-read the raw files to refute the
central claims; all three returned *confirmed*. Where the workflow's reconcile pass
over-corrected (it briefly claimed `_BLT-295C` had no 295 °C source), the first-hand grep
above overrides it: `_BLT-295C/Configuration.h:624` does read `HEATER_0_MAXTEMP 295`.

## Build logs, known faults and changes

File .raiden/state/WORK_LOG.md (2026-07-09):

# Work Log

## 2026-07-08 — RAIDEN Instance install

- Fleet scan (RAIDEN-ops LOOP-0021) identified SW-X1 as an active,
  git-managed project with no RAIDEN Instance.
- Created GitHub remote `StarlightDaemon/SW-X1` (public); initial push was
  blocked by GitHub's private-email policy on the pre-existing commits.
- Rewrote the 4 pre-install commits to the `StarlightDaemon` fleet git
  identity (D-001) and pushed `main`.
- Installed RAIDEN Instance at Edict v1.0.0: `.raiden/writ/` populated from
  the six-file managed payload, commit-msg hook installed, root `AGENTS.md`
  startup bridge written, D-0038 gitignore block appended.

## 2026-07-09 — Edict v2.0.0 + state normalization

- Applied Edict update 1.0.1 → 2.0.0 via `raiden_updater.cli` (plan then
  apply, both clean): added `ROUTING_POLICY.md`; removed `MODEL_TIERS.md`
  (managed file absent from new package, flagged `managed_file_removal` warn,
  safe per baseline); updated `README.md`, `OPERATING_RULES.md`,
  `WORKSPACE_AUDIT_PROTOCOL.md`, `FORK_REVIEW_PROTOCOL.md`, `AGENTS.md`;
  `hooks/commit-msg` unchanged. Re-plan confirmed "Already up to date".
- Stamped `"state_schema_version": 2` into `.raiden/instance/metadata.json`.
- Routing overlay: removed `.raiden/local/MODEL_MAP.md` (tier-to-model
  mapping, superseded); added `.raiden/local/ROUTING.md` (rung-ladder model
  routing, R1-R4 plus offload pool).
- State normalization per the new Writ's Fact-Home Rule and Cross-Repo
  Citation Namespace (`.raiden/writ/OPERATING_RULES.md`):
  - Dangling ref fix: `LOOP-0021` citations in `CURRENT_STATE.md` (Summary
    and Provenance) rewritten as `Raiden-ops:LOOP-0021` — it is a
    Raiden-ops loop, not a local one.
  - Removed hand-written "installed ... at Edict v1.0.0" / "(Edict v1.0.0)"
    version-prose strings from `CURRENT_STATE.md` (two instances),
    `GOALS.md`, and `OPEN_LOOPS.md` Provenance sections — the fact is
    already the authoritative record above (2026-07-08 entry) and in
    `.raiden/instance/metadata.json`; no unique history was lost.
  - No hand-written "Last Updated:"/"Last Verified:" footer lines were
    found in any `.raiden/state/` file (checked `CURRENT_STATE.md`,
    `GOALS.md`, `OPEN_LOOPS.md`, `DECISIONS.md`, `WORK_LOG.md`); none to
    remove.
  - LOOP-001/LOOP-002 (BLTouch hardware, `OPEN_LOOPS.md`) left as-is —
    hardware-gated, out of scope for this pass.

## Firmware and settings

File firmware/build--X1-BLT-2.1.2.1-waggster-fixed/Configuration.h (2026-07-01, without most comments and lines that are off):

#pragma once
#define CONFIG_EXAMPLES_DIR "config/examples/Artillery/Sidewinder X1/V1-BL"
#define CONFIGURATION_H_VERSION 02010201
#define STRING_CONFIG_H_AUTHOR "(dgtaheno, Genius)" // Who made the changes.
#define SHOW_BOOTSCREEN
  #define MOTHERBOARD BOARD_MKS_GEN_L
#define SERIAL_PORT 0
#define BAUDRATE 250000
#define CUSTOM_MACHINE_NAME "Sidewinder X1"
#define X_DRIVER_TYPE  TMC2100
#define Y_DRIVER_TYPE  TMC2100
#define Z_DRIVER_TYPE  TMC2100
#define Z2_DRIVER_TYPE TMC2100
#define E0_DRIVER_TYPE TMC2100
#define EXTRUDERS 1
#define DEFAULT_NOMINAL_FILAMENT_DIA 1.75
#define TEMP_SENSOR_0 1
#define TEMP_SENSOR_1 0
#define TEMP_SENSOR_2 0
#define TEMP_SENSOR_3 0
#define TEMP_SENSOR_4 0
#define TEMP_SENSOR_5 0
#define TEMP_SENSOR_6 0
#define TEMP_SENSOR_7 0
#define TEMP_SENSOR_BED 1
#define TEMP_SENSOR_PROBE 0
#define TEMP_SENSOR_CHAMBER 0
#define TEMP_SENSOR_COOLER 0
#define TEMP_SENSOR_BOARD 0
#define TEMP_SENSOR_REDUNDANT 0
#define DUMMY_THERMISTOR_998_VALUE  25
#define DUMMY_THERMISTOR_999_VALUE 100
#if TEMP_SENSOR_IS_MAX_TC(0)
  #define MAX31865_SENSOR_OHMS_0      100 // (Ω) Typically 100 or 1000 (PT100 or PT1000)
  #define MAX31865_CALIBRATION_OHMS_0 430 // (Ω) Typically 430 for Adafruit PT100; 4300 for Adafruit PT1000
#endif
#if TEMP_SENSOR_IS_MAX_TC(1)
  #define MAX31865_SENSOR_OHMS_1      100
  #define MAX31865_CALIBRATION_OHMS_1 430
#endif
#if TEMP_SENSOR_IS_MAX_TC(2)
  #define MAX31865_SENSOR_OHMS_2      100
  #define MAX31865_CALIBRATION_OHMS_2 430
#endif
#if HAS_E_TEMP_SENSOR
  #define TEMP_RESIDENCY_TIME         10  // (seconds) Time to wait for hotend to "settle" in M109
  #define TEMP_WINDOW                  1  // (°C) Temperature proximity for the "temperature reached" timer
  #define TEMP_HYSTERESIS              5  // (°C) Temperature proximity considered "close enough" to the target
#endif
#if TEMP_SENSOR_BED
  #define TEMP_BED_RESIDENCY_TIME     10  // (seconds) Time to wait for bed to "settle" in M190
  #define TEMP_BED_WINDOW              1  // (°C) Temperature proximity for the "temperature reached" timer
  #define TEMP_BED_HYSTERESIS          3  // (°C) Temperature proximity considered "close enough" to the target
#endif
#if TEMP_SENSOR_CHAMBER
  #define TEMP_CHAMBER_RESIDENCY_TIME 10  // (seconds) Time to wait for chamber to "settle" in M191
  #define TEMP_CHAMBER_WINDOW          1  // (°C) Temperature proximity for the "temperature reached" timer
  #define TEMP_CHAMBER_HYSTERESIS      3  // (°C) Temperature proximity considered "close enough" to the target
#endif
#if TEMP_SENSOR_REDUNDANT
  #define TEMP_SENSOR_REDUNDANT_SOURCE    E1  // The sensor that will provide the redundant reading.
  #define TEMP_SENSOR_REDUNDANT_TARGET    E0  // The sensor that we are providing a redundant reading for.
  #define TEMP_SENSOR_REDUNDANT_MAX_DIFF  10  // (°C) Temperature difference that will trigger a print abort.
#endif
#define HEATER_0_MINTEMP   5
#define HEATER_1_MINTEMP   5
#define HEATER_2_MINTEMP   5
#define HEATER_3_MINTEMP   5
#define HEATER_4_MINTEMP   5
#define HEATER_5_MINTEMP   5
#define HEATER_6_MINTEMP   5
#define HEATER_7_MINTEMP   5
#define BED_MINTEMP        5
#define CHAMBER_MINTEMP    5
#define HEATER_0_MAXTEMP 275
#define HEATER_1_MAXTEMP 275
#define HEATER_2_MAXTEMP 275
#define HEATER_3_MAXTEMP 275
#define HEATER_4_MAXTEMP 275
#define HEATER_5_MAXTEMP 275
#define HEATER_6_MAXTEMP 275
#define HEATER_7_MAXTEMP 275
#define BED_MAXTEMP      150
#define CHAMBER_MAXTEMP  60
#define HOTEND_OVERSHOOT 15   // (°C) Forbid temperatures over MAXTEMP - OVERSHOOT
#define BED_OVERSHOOT    10   // (°C) Forbid temperatures over MAXTEMP - OVERSHOOT
#define COOLER_OVERSHOOT  2   // (°C) Forbid temperatures closer than OVERSHOOT
#define PIDTEMP          // See the PID Tuning Guide at https://reprap.org/wiki/PID_Tuning
#define BANG_MAX 255     // Limits current to nozzle while in bang-bang mode; 255=full current
#define PID_MAX BANG_MAX // Limits current to nozzle while PID is active (see PID_FUNCTIONAL_RANGE below); 255=full current
#define PID_K1 0.95      // Smoothing factor within any PID loop
    #define DEFAULT_Kp  14.58
    #define DEFAULT_Ki   1.14
    #define DEFAULT_Kd  46.57
#define PIDTEMPBED
#define MAX_BED_POWER 255 // limits duty cycle to bed; 255=full current
  #define DEFAULT_bedKp 244.21
  #define DEFAULT_bedKi 45.87
  #define DEFAULT_bedKd 325.08
#define MAX_CHAMBER_POWER 255 // limits duty cycle to chamber heater; 255=full current
  #define PID_FUNCTIONAL_RANGE 10 // If the temperature difference between the target temperature and the actual temperature
#define PREVENT_COLD_EXTRUSION
#define EXTRUDE_MINTEMP 170
#define PREVENT_LENGTHY_EXTRUDE
#define EXTRUDE_MAXLENGTH 200
#define THERMAL_PROTECTION_HOTENDS // Enable thermal protection for all extruders
#define THERMAL_PROTECTION_BED     // Enable thermal protection for the heated bed
#define THERMAL_PROTECTION_CHAMBER // Enable thermal protection for the heated chamber
#define THERMAL_PROTECTION_COOLER  // Enable thermal protection for the laser cooling
#define USE_XMIN_PLUG
#define USE_YMIN_PLUG
#define USE_ZMIN_PLUG
#define ENDSTOPPULLUPS
#define X_MIN_ENDSTOP_INVERTING true  // Set to true to invert the logic of the endstop.
#define Y_MIN_ENDSTOP_INVERTING true  // Set to true to invert the logic of the endstop.
#define Z_MIN_ENDSTOP_INVERTING false  // Set to true to invert the logic of the endstop.
#define I_MIN_ENDSTOP_INVERTING false // Set to true to invert the logic of the endstop.
#define J_MIN_ENDSTOP_INVERTING false // Set to true to invert the logic of the endstop.
#define K_MIN_ENDSTOP_INVERTING false // Set to true to invert the logic of the endstop.
#define U_MIN_ENDSTOP_INVERTING false // Set to true to invert the logic of the endstop.
#define V_MIN_ENDSTOP_INVERTING false // Set to true to invert the logic of the endstop.
#define W_MIN_ENDSTOP_INVERTING false // Set to true to invert the logic of the endstop.
#define X_MAX_ENDSTOP_INVERTING false // Set to true to invert the logic of the endstop.
#define Y_MAX_ENDSTOP_INVERTING false // Set to true to invert the logic of the endstop.
#define Z_MAX_ENDSTOP_INVERTING false // Set to true to invert the logic of the endstop.
#define I_MAX_ENDSTOP_INVERTING false // Set to true to invert the logic of the endstop.
#define J_MAX_ENDSTOP_INVERTING false // Set to true to invert the logic of the endstop.
#define K_MAX_ENDSTOP_INVERTING false // Set to true to invert the logic of the endstop.
#define U_MAX_ENDSTOP_INVERTING false // Set to true to invert the logic of the endstop.
#define V_MAX_ENDSTOP_INVERTING false // Set to true to invert the logic of the endstop.
#define W_MAX_ENDSTOP_INVERTING false // Set to true to invert the logic of the endstop.
#define Z_MIN_PROBE_ENDSTOP_INVERTING false // Set to true to invert the logic of the probe.
#define ENDSTOP_NOISE_THRESHOLD 2
#define DEFAULT_AXIS_STEPS_PER_UNIT   { 80, 80, 400, 445 }
#define DEFAULT_MAX_FEEDRATE          { 300, 300, 50, 40 }
#define DEFAULT_MAX_ACCELERATION      { 2000, 2000, 100, 10000 }
#define DEFAULT_ACCELERATION           800    // X, Y, Z and E acceleration for printing moves
#define DEFAULT_RETRACT_ACCELERATION 10000    // E acceleration for retracts
#define DEFAULT_TRAVEL_ACCELERATION   2000    // X, Y, Z acceleration for travel (non printing) moves
#define DEFAULT_EJERK    5.0  // May be used by Linear Advance
  #define JUNCTION_DEVIATION_MM 0.032 // (mm) Distance from real junction edge
  #define JD_HANDLE_SMALL_SEGMENTS    // Use curvature estimation instead of just the junction angle
#define S_CURVE_ACCELERATION
#define USE_PROBE_FOR_Z_HOMING
#define Z_MIN_PROBE_PIN 19 // Pin 32 is the RAMPS default
#define BLTOUCH
#define NOZZLE_TO_PROBE_OFFSET { 25.4, -26.4, -1 }
#define PROBING_MARGIN 10
#define XY_PROBE_FEEDRATE (133*60)
#define Z_PROBE_FEEDRATE_FAST (20*60)
#define Z_PROBE_FEEDRATE_SLOW (Z_PROBE_FEEDRATE_FAST / 2)
#define Z_CLEARANCE_DEPLOY_PROBE   10 // Z Clearance for Deploy/Stow
#define Z_CLEARANCE_BETWEEN_PROBES  5 // Z Clearance between probe points
#define Z_CLEARANCE_MULTI_PROBE     5 // Z Clearance between multiple probes
#define Z_PROBE_LOW_POINT          -2 // Farthest distance below the trigger-point to go before stopping
#define Z_PROBE_OFFSET_RANGE_MIN -20
#define Z_PROBE_OFFSET_RANGE_MAX 20
#define X_ENABLE_ON 0
#define Y_ENABLE_ON 0
#define Z_ENABLE_ON 0
#define E_ENABLE_ON 0 // For all extruders
#define DISABLE_X false
#define DISABLE_Y false
#define DISABLE_Z false
#define DISABLE_E false             // Disable the extruder when not stepping
#define DISABLE_INACTIVE_EXTRUDER   // Keep only the active extruder enabled
#define INVERT_X_DIR false
#define INVERT_Y_DIR false
#define INVERT_Z_DIR true
#define INVERT_E0_DIR false
#define INVERT_E1_DIR false
#define INVERT_E2_DIR false
#define INVERT_E3_DIR false
#define INVERT_E4_DIR false
#define INVERT_E5_DIR false
#define INVERT_E6_DIR false
#define INVERT_E7_DIR false
#define X_HOME_DIR -1
#define Y_HOME_DIR -1
#define Z_HOME_DIR -1
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

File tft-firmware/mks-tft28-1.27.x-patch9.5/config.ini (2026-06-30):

#--------------------------------------------------------------------
#
# DEFAULT CONFIG FILE FOR BigTreeTech TFT CONTROLLERS
#
#--------------------------------------------------------------------


#--------------------------------------------------------------------
# Supported TFT Variants
#--------------------------------------------------------------------
#
# BIGTREE_TFT24_V1_1    / BIGTREE_TFT28_V1_0 / BIGTREE_TFT28_V3_0
# BIGTREE_TFT35_V1_0    / BIGTREE_TFT35_V1_1 / BIGTREE_TFT35_V1_2
# BIGTREE_TFT35_V2_0    / BIGTREE_TFT35_V3_0 / BIGTREE_TFT35_E3_V3_0
# BIGTREE_TFT35_B1_V3_0 / BIGTREE_TFT43_V3_0 / BIGTREE_TFT50_V3_0
# BIGTREE_TFT70_V3_0
#
# BIGTREE_GD_TFT24_V1_1    / BIGTREE_GD_TFT35_V2_0    / BIGTREE_GD_TFT35_V3_0
# BIGTREE_GD_TFT35_E3_V3_0 / BIGTREE_GD_TFT35_B1_V3_0 / BIGTREE_GD_TFT43_V3_0
# BIGTREE_GD_TFT50_V3_0    / BIGTREE_GD_TFT70_V3_0
#
# MKS_TFT28_V3_0 / MKS_TFT28_V4_0 / MKS_TFT28_NEW_GENIUS
# MKS_TFT32_V1_3 / MKS_TFT32_V1_4 / MKS_TFT32L_V3_0
# MKS_TFT35_V1_0
#
# Firmware source: https://github.com/bigtreetech/BIGTREETECH-TouchScreenFirmware


#--------------------------------------------------------------------
# Supported Marlin Firmware Versions
#--------------------------------------------------------------------
#
# Minimum Marlin firmware version: 2.1.1
# Distribution date: 2022-09-22
# Firmware source: https://github.com/MarlinFirmware/Marlin/releases
#
# To use all the features and functionalities supported by the TFT,
# the following options must be enabled in Marlin firmware.
#
# General options which MUST be always activated:
#   EEPROM_SETTINGS (in Configuration.h)
#   BABYSTEPPING (in Configuration_adv.h)
#   AUTO_REPORT_TEMPERATURES (in Configuration_adv.h)
#   AUTO_REPORT_POSITION (in Configuration_adv.h)
#   EXTENDED_CAPABILITIES_REPORT (in Configuration_adv.h)
#   M115_GEOMETRY_REPORT (in Configuration_adv.h)
#   M114_DETAIL (in Configuration_adv.h)
#   REPORT_FAN_CHANGE (in Configuration_adv.h)
#
# Options to support printing from onboard media:
#   SDSUPPORT (in Configuration.h)
#   LONG_FILENAME_HOST_SUPPORT (in Configuration_adv.h)
#   AUTO_REPORT_SD_STATUS (in Configuration_adv.h)
#   SDCARD_CONNECTION ONBOARD (in Configuration_adv.h)
#
# Options to support dialog with host:
#   EMERGENCY_PARSER (in Configuration_adv.h)
#   SERIAL_FLOAT_PRECISION 4 (in Configuration_adv.h)
#   HOST_ACTION_COMMANDS (in Configuration_adv.h)
#   HOST_PROMPT_SUPPORT (in Configuration_adv.h)
#   HOST_STATUS_NOTIFICATIONS (in Configuration_adv.h)
#
# Options to support M73 with host:
#   Options to support dialog with host (as pre requisite)
#   SET_PROGRESS_MANUALLY (in Configuration_adv.h)
#   M73_REPORT (in Configuration_adv.h)
#
# Options to support M600 with host & (Un)Load menu:
#   Options to support dialog with host (as pre requisite)
#   NOZZLE_PARK_FEATURE (in Configuration.h)
#   ADVANCED_PAUSE_FEATURE (in Configuration_adv.h)
#   PARK_HEAD_ON_PAUSE (in Configuration_adv.h)
#   FILAMENT_LOAD_UNLOAD_GCODES (in Configuration_adv.h)
#
# Options to fully support Bed Leveling menu:
#   Z_MIN_PROBE_REPEATABILITY_TEST (in Configuration.h)
#   G26_MESH_VALIDATION (in Configuration.h)
#   Z_STEPPER_AUTO_ALIGN (in Configuration_adv.h)


#--------------------------------------------------------------------
# General Settings
#--------------------------------------------------------------------

#### Serial Ports (Primary and Supplementary)
# Serial ports connected to devices such as Printer, ESP3D, OctoPrint and other Controllers.
# In order to successfully establish a communication through a serial port, set a baudrate
# matching the baudrate configured on the connected device.
# Disable the serial port when it is not in use and/or not connected to a device (floating) to
# avoid to receive and process wrong data due to possible electromagnetic interference (EMI).
#
# NOTES:
#   - Serial port P1 is the primary serial connection to the printer and cannot be disabled.
#   - A baudrate of 250000 works in most cases, but you can try a lower speed if you
#     commonly experience drop-outs during host printing.
#     You may try up to 1000000 to speed up SD file transfer.
#
#   Format: [serial_port: P1:<baudrate> P2:<baudrate> P3:<baudrate> P4:<baudrate>
#   Target port: P1: Printer
#                P2: WIFI    (e.g. ESP3D)
#                P3: UART 3  (e.g. OctoPrint)
#                P4: UART 4
#   Value range: P1: [min: 1, max: 9]
#                P2: [min: 0, max: 9]
#                P3: [min: 0, max: 9]
#                P4: [min: 0, max: 9]
#   Options: [OFF (port disabled): 0, 2400: 1, 9600: 2, 19200: 3, 38400: 4, 57600: 5, 115200: 6, 250000: 7, 500000: 8, 1000000: 9]
serial_port:P1:7 P2:0 P3:0 P4:0
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

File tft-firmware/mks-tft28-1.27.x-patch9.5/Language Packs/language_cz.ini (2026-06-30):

#### Language Code:CZ
## Language Version:20230209
## Maximum byte per keyword is 250 Bytes.
## Escape characters are not supported except newline '\n'

label_language:Čeština
label_emulated_m600:Emulace M600
label_emulated_m109_m190:Emulace M109 / M190
label_event_led:LED události
label_file_comment_parsing:Analýzovat komentáře
label_rotated_ui:Otočit UI
label_ack_notification:Styl oznámení ACK
label_files_sort_by:Řazení souboru
label_files_list_mode:Soubory jako seznam
label_filename_extension:Zobrazit příponu souboru
label_fan_speed_percentage:Rychlost ventilátoru v %
label_persistent_info:Zobrazení stavových ikon
label_terminal_ack:zobrazit ACK Terminálu
label_serial_always_on:Sériový port vždy ON
label_marlin_fullscreen:Fullscreen režim Marlin
label_marlin_show_title:Zobrazit tytulek Marlin
label_marlin_type:Typ Marlin Modu
label_move_speed:Rychlost pohybu X Y Z
label_auto_load_leveling:Automaticky Leveling
label_probing_z_offset:Sondování pro Z offset
label_z_steppers_alignment:Z motor Auto-Alignment
label_ps_auto_shutdown:Auto.vypnutí
label_fil_runout:Senzor filamentu
label_pl_recovery:Obnova po ztrátě napájení
label_pl_recovery_home:Spuštění obnovení napájení
label_btt_mini_ups:Podpora BTT UPS
label_touch_sound:Zvuk při dotyku
label_toast_sound:Zvuk oznámení
label_alert_sound:Zvuk popup okna
label_heater_sound:Zvuk při dosažení teploty
label_lcd_brightness:LCD jas
label_lcd_idle_brightness:LCD snížení jasu
label_lcd_idle_time:LCD snížení jasu po
label_lcd_lock_on_idle:Blok. dotek při zatmavení
label_led_always_on:LED vždy zapnuto
label_knob_led_color:Rotační knob LED
label_knob_led_idle:Rotační knob LED idle
label_start_gcode_enabled:Spustit Gcode před tiskem
label_end_gcode_enabled:Spustit Gcode po tisku
label_cancel_gcode_enabled:Spustit Gcode po stornu
label_steps_setting:Kroky/mm
label_filament_setting:Pruměr Filamentu
label_maxacceleration:Max zrychlení
label_maxfeedrate:Max rychlost
label_acceleration:Zrychlení
label_jerk:Jerk-trhnutí
label_junction_deviation:Junction Deviation
label_home_offset:Home Offset
label_fwretract:FW Zatažení
label_fwrecover:FW Obnovení
label_retract_auto:Auto Firmware Retract
label_hotend_offset:Offset 2.trysky
label_hotend_pid:PID trysky
label_bed_pid:PID podložky
label_stealth_chop:TMC Tichý režim
label_input_shaping:Input Shaping
label_delta_configuration:Delta konfigurace
label_delta_tower_angle:Úhel věže
label_delta_diagonal_rod:Diagonální tyč
label_delta_endstop:Nastavení dorazu
label_probe_offset:Offset sondy
label_lin_advance:Linear Advance
label_current_setting:TMC Proud motoru(mA)
label_hybrid_threshold:TMC Hybridní práh
label_bump_sensitivity:TMC Citlivost dorazu
label_mbl_offset:MBL Offset
label_print_acceleration:Zrychlení při tisku
label_retract_acceleration:Zrychlení retrakcí
label_travel_acceleration:Zrychlení při přesunu
label_retract_length:Délka zatažení
label_retract_swap_length:Délka zatažení Swap
label_retract_feedrate:Rychlost zatažení
label_retract_z_lift:Z zvýšení při zatažení
label_recover_length:Délka obnovení
label_swap_recover_length:Délka obnovení Swap
label_recover_feedrate:Rychlost obnovení
label_swap_recover_feedrate:Rychlost obnovení Swap
label_save:Uložit
label_restore:Obnovit
label_reset:Reset
label_eeprom_save_info:Uložit nastavení tiskárny do EEPROM?
label_eeprom_restore_info:Obnovit nastavení z EEPROM?
label_eeprom_reset_info:Reset EEPROM na výchozí hodnoty?
label_settings_save:Uložení nastavení
label_settings_restore:Obnovení nastavení
label_settings_reset:Reset nastavení
label_settings_reset_info:Obnovit všechna nastavení na výchozí hodnoty?
label_settings_reset_done:Obnovení všech nastavení bylo úspěšně provedeno.\nRestartujte zařízení.
label_page_up:Další
label_page_down:Předchozí
label_up:Nahoru
label_down:Dolu
label_next:Další
label_back:Zpět
label_inc:Přidat
label_dec:Ubrat
label_load:Zavést
label_unload:Vysunout
label_on:ON
label_off:OFF
label_auto:AUTO
label_smart:SMART
label_slow:Pomalu
label_normal:Normál
label_fast:Rychle
label_zero:Vynulovat
label_half:Poloviční
label_full:Plný
label_custom:Vlastní
label_clear:Vymaž
label_default:Výchozí
label_start:Start
label_stop:Stop
label_pause:Pauza
label_resume:Obnovit
label_init:Init
label_disconnect:Odpojit
label_shut_down:Vypnout
label_force_shut_down:Vynutit
label_emergencystop:!!STOP!!
label_preheat:Zahřát
label_preheat_both:Vše
label_cooldown:Zchladit
label_confirm:Potvrdit
label_cancel:Zrušit
label_warning:Varování
label_continue:Pokračovat
label_confirmation:Jste si jistý?
label_status:Status
label_ready:Připraven
label_busy:Zpracovávám, čekejte prosím...
label_loading:Nahrávám...
label_unconnected:Tiskárna není připojena!
label_listening:TFT v režimu naslouchání!
label_info:Info
label_invalid_value:Neplatná hodnota/y!
label_timeout_reached:Časový limit vypršel!
label_disconnect_info:Nyní mužete tiskárnu ovládat z počítače!
label_shutting_down:Vypínám se...
label_wait_temp_shut_down:Čekám na zchladnutí trysky pod %d℃
label_power_failed:Obnovit tisk?
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

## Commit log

2026-06-30 Initial Sidewinder X1 firmware & tooling maintenance workspace
    Locally-owned, upstream-independent record for one Artillery Sidewinder X1
    (Gen1 Rev1) being recommissioned. Collected and verified by direct source
    inspection (not by trusting filenames/changelogs):
    - 4 upstream repos cloned 2026-06-30; full git bundles archived for survival
    independent of upstream (archive/upstream-bundles/ + SOURCES.md).
    - Curated firmware: running X1 non-BLT, target X1-BLT, digant73 canonical
    Waggster (z-max), Genius BLT refs, mbl, peterrakolcza 2.1.2 binaries,
    artillery3d stock. MD5 fingerprints in firmware/NOTES.md.
    - TFT firmware, Waggster cabling PDF, printed parts, EEPROM-reset gcode.
    Key verifie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
    [Configuration.h, Configuration_adv.h, Gantry Square.STL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]
2026-07-01 Add ready-to-flash corrected firmware + install runbook
    Pre-arrival readiness for the incoming BLTouch:
    - firmware/build--X1-BLT-2.1.2.1-waggster-fixed/: dgtaheno's Marlin 2.1.2.1
    X1-BLT REBUILT with the probe-pin fix (Configuration.h line 1279,
    Z_MIN_PROBE_USES_Z_MIN_ENDSTOP_PIN, commented out). Compiled clean via
    PlatformIO for env mega2560 (Flash 45.7%, RAM 84.9%); artifact
    Marlin-2.1.2.1-X1-BLT-waggster-fixed.hex (326346 B, md5 ddde4fc3...),
    within 274 B of dgtaheno's official build -> faithful rebuild + fix.
    Verified the compiled tree routes probe to Z-MAX/pin 19. BUILD.md documents
    a full reproduce recipe.
    - docs/install-runbook.md: single flash-day checklist (pre-fligh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
    [Configuration.h, Configuration_adv.h]
2026-07-01 Add BLTouch mount+duct research, recommendation & print-shop spec
    Researched the best BLTouch mount that handles part-cooling airflow (for a
    print service), then verified candidates hands-on via the logged-in Thingiverse
    browser session. Corrected a hallucinated web-research lead: Thingiverse
    thing:3972011 does not exist (verified 404).
    Real, verified options (printed-parts/BLTOUCH-MOUNT-OPTIONS.md):
    - A) Integrated single part: blinkybill thing:4606514
    'Fan_Mount_With_Duct_And_BL-Touch.stl' (mount+duct+BLTouch in one).
    - B) Best cooling: Waggster mount (already vendored) + alguiens 'Futuristic'
    duct thing:4368198 (long-reach tip cooling) or '~180' duct thing:4360786.
    - 3DPrintBeginner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
2026-07-01 Vendor all mount/duct STLs + add master build guide
    Saved every BLTouch mount/duct option locally (pulled via the logged-in
    Thingiverse session; each verified as a valid binary STL, MD5s recorded):
    - waggster-bltouch-mount-duct/ (Option A, blinkybill thing:4606514):
    Fan_Mount_With_Duct_And_BL-Touch.stl (+ No-BLTouch, Slider).
    - fan-duct-remix/ (Option B ducts, alguiens): Futuristic (thing:4368198) and
    ~180 (thing:4360786). CC BY-NC — flagged for commercial print shops.
    - waggster-bltouch-mount/ (Waggster originals thing:3716043): Adjustable,
    Slider, Calibration (+ existing digant73 SWX1-BLT-Bracket.stl).
    Corrected the earlier research error in-repo (thing:3972011 does not exist).
    d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
    [Artillery_Sidewinder_X1_Futuristic_fan_duct_for_BLTouch_mount.stl, BLTouch_Calibration.stl, BLTouch_Mount_Adjustable.stl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]
2026-07-09 chore(raiden): Phase B remediation — bridge, routing
2026-07-09 chore: update RAIDEN Instance to Edict v2.0.0 + state normalization
    - Applied Edict v2.0.0 (1.0.1 -> 2.0.0): add ROUTING_POLICY.md, remove
    MODEL_TIERS.md, update managed writ files; hook unchanged.
    - Stamp state_schema_version=2 in .raiden/instance/metadata.json.
    - Replace local/MODEL_MAP.md tier mapping with local/ROUTING.md rung
    ladder (R1-R4 + offload pool), per the v2.0.0 routing model.
    - Normalize state prose per the new Fact-Home Rule and Cross-Repo
    Citation Namespace: fix LOOP-0021 dangling ref to Raiden-ops:LOOP-0021,
    drop redundant Edict-version strings from CURRENT_STATE/GOALS/OPEN_LOOPS
    (already recorded in the 2026-07-08 WORK_LOG entry and metadata.json),
    and log the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
2026-07-09 chore(raiden): redact personal identity from D-001 narrative
    Redacts live/current exposure only; history purge is a later phase.
2026-07-15 chore(raiden): de-path bridge - migrate local paths to Windows Citadel root (E:\Citadel)

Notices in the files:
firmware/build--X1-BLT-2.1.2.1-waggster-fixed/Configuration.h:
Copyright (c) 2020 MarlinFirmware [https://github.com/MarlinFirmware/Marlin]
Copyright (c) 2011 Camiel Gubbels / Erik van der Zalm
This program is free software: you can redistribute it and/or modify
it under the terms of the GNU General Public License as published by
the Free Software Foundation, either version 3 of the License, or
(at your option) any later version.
